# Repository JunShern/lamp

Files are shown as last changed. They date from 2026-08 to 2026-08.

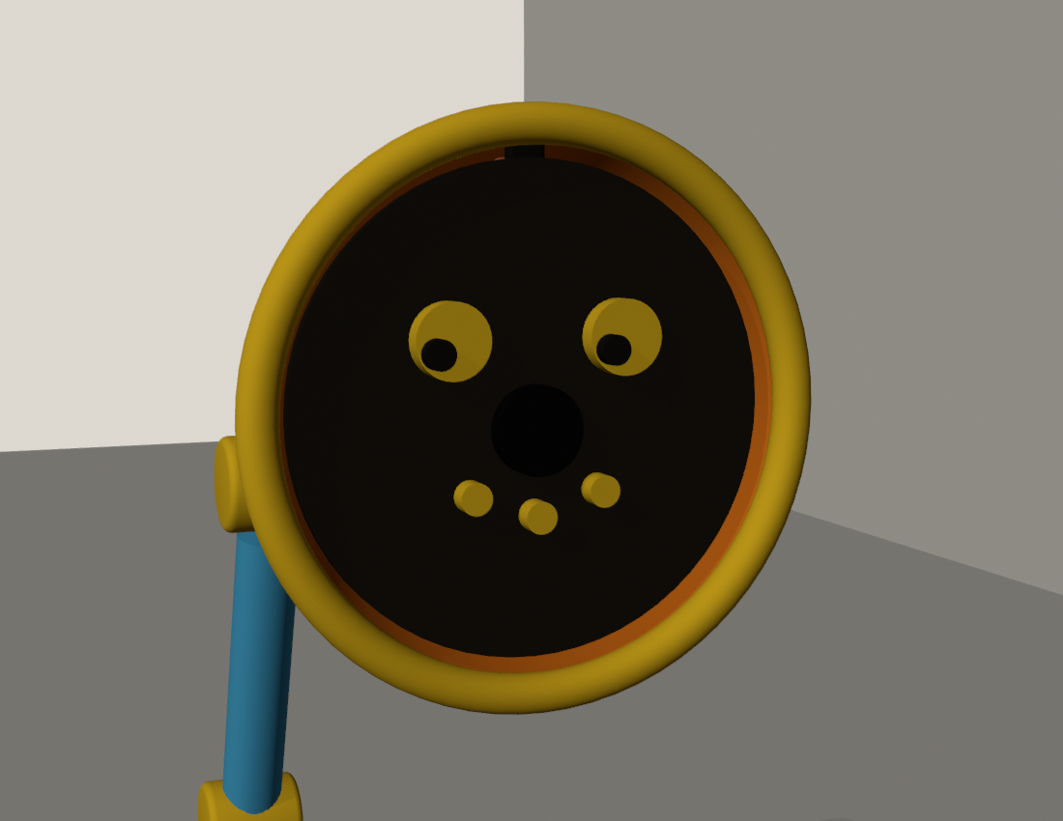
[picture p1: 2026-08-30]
cad/renders/lamp_duck_face.png

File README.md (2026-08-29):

# Lamp

A Pixar-style animatronic desk lamp: silent, expressive, and alive.

It listens (mic array), perceives without a camera (multizone time-of-flight),
thinks (Claude), and answers entirely through **motion**, a **16×16 projected
pixel display**, and **piezo chirps**. No voice, ever — the character is the
interface.

- **Design doc:** [docs/DESIGN.md](docs/DESIGN.md)
- **Bill of materials:** [docs/BOM.md](docs/BOM.md)
- **Status:** concept settled, design phase in progress.

## Repository layout (planned)

```
docs/       design doc, BOM, decisions
assets/     emotes, glyphs, chirps (JSON) — the shared contract
cad/        parametric Blender (bpy) model, renders, massing STLs
sim/        browser simulator (build: python3 sim/build.py)
lamp/       Python engine for the Raspberry Pi (validate: python3 -m lamp.validate)
tests/      pytest suite incl. envelope sweep (python3 -m pytest tests/)
```

The browser simulator and the Python engine implement the same spring/keyframe
physics over the same asset files and are cross-validated against each other —
what you tune in the simulator is what the hardware will do.

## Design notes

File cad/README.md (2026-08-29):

# CAD

`lamp_preview.py` — parametric massing model of the lamp, runnable headless
with Blender-as-a-module (`pip install bpy`). Builds the whole lamp in the
neutral pose from a single PARAMS dict (same joint angles as
`../assets/emotes.json`), renders design-review images (Workbench engine)
in three MicroDuck-inspired colourways, and exports massing STLs.

- `renders/` — design review renders
- `preview_stl/` — **massing shells only** — proportions and silhouettes for
  review, NOT print-ready engineering parts (no servo pockets, walls,
  fasteners, or clearances yet; those come in Phase 3)

Run: `python3 cad/lamp_preview.py`

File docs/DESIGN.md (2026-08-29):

# Design Document — Pixar-Style Animatronic Lamp

Status: **draft for review** · Last updated: 2026-08-29

## 1. Vision

A desk lamp with the soul of Luxo Jr.: a silent, expressive robot that lives on
a desk (or shelf), listens when spoken to, and responds only through **motion**,
a **projected 16×16 pixel display**, and **non-verbal piezo chirps**. Claude is
the mind; the body is the interface.

Guiding principles, in priority order:

1. **Motion quality is the product.** Anticipation, ease-in/ease-out, follow-through,
   secondary motion, gaze. A lamp that moves beautifully and does little beats a
   lamp that does everything and moves like a printer.
2. **Constraint is character.** 256 pixels and a piezo beeper are the *native
   medium*, not placeholders. The visual/sound language is designed for them.
3. **Privacy by physics.** No camera. Perception uses sensors that are
   incapable of producing imagery: a multizone time-of-flight depth sensor and
   a microphone array. Audio is processed on-device; only text leaves the lamp.
4. **Modular head.** The display module bolts to a standard interface so it can
   be swapped (light ring → matrix projector → anything else) without redesign.

Prior art worth stealing from: Pixar's *Luxo Jr.* (staging and timing), Apple's
**ELEGNT** research paper (Jan 2025 — expressive movement design for a
non-anthropomorphic lamp robot; strong taxonomy of functional vs. expressive
motion), and the SO-ARM100/101 open-source arms (proven low-cost serial-bus
servo mechanics).

## 2. Settled decisions

| # | Decision | Choice | Notes |
|---|---|---|---|
| D1 | Voice | **None.** Motion + projection + chirps only | Canonical Luxo behavior; removes TTS/latency pressure |
| D2 | Display | **Fine-pitch WS2812 matrix + projection lens**, likely final form. Grid = the panel's native resolution (16×16 minimum, likely 22×22) | Head interface stays modular as cheap insurance; all software resolution-parametric, glyph art finalized once the panel is verified in hand |
| D3 | Sound | **Passive piezo**, PWM-driven chirps | No speaker, no audio DAC; "Game Boy" palette |
| D4 | Camera | **Never in v1.** ToF depth grid + mic DOA only | Camera module possible later, with hardware shutter + power LED |
| D5 | Power | Mains, single external 12 V PSU into the base | No battery |
| D6 | Compute | Raspberry Pi 5 (8 GB) in the base | Headroom for local STT |
| D7 | Actuators | 5× Feetech ST3215 serial-bus servos (12 V, 30 kg·cm) | Position feedback, daisy-chain, ~£15 each |
| D8 | Size | ~40 cm tall upright, base ~180 mm ⌀ | Luxo Jr. presence, desk-friendly |
| D9 | Fabrication | Bambu Lab A1 (256×256×256 mm bed), PETG/PLA | Every part fits the bed; base prints in one piece |
| D10 | CAD | Blender with parametric `bpy` scripts in `cad/` | Regenerable geometry, STL export |
| D11 | Budget | £300–500 all-in | Current estimate ~£350, see BOM |

Open questions (fine to defer):

- O1 (direction settled, colourway open): shell design language follows
  Pollen Robotics' MicroDuck — matte pastel printed shell with **one warm
  saturated accent** on the mechanical hero parts (joint caps, shade rim,
  yaw disc), black reserved for optics, articulation honestly visible.
  Candidate colourways (see cad/renders/): cream `#F7E6CB`/orange (proposed),
  sky `#A9DBE8`/orange, graphite `#6C6A68`/yellow. A MicroDuck-style
  **REC-tally "listening" dot** on the shade lights only when the mic is
  live (hardwired to mic power, not software). Exact proportions still
  iterate in Blender.
- O2: Whether the shoulder needs spring counterbalance (decide after torque
  test on the bench; mounting bosses for a spring are designed in regardless).
- O3: Local STT (faster-whisper on the Pi) vs. cloud STT — start local for
  privacy; fall back if latency disappoints.

## 3. System overview

```mermaid
flowchart LR
    subgraph Head
        TOF[ToF 8x8 depth sensor]
        MATRIX[16x16 LED matrix]
        LENS[Projection lens + focus servo]
        PIEZO[Piezo chirper]
    end
    subgraph Arm
        S1[5x ST3215 bus servos]
    end
    subgraph Base
        MIC[USB mic array w/ DOA]
        PI[Raspberry Pi 5]
        PSU[12V PSU + 5V buck]
        DRV[Bus servo driver board]
    end
    MIC -->|"wake word + speech + direction"| PI
    TOF -->|I2C depth grid| PI
    PI -->|UART bus| DRV --> S1
    PI -->|SPI/PIO pixel data| MATRIX
    PI -->|PWM| PIEZO
    PI -->|PWM| LENS
    PI <-->|"text + tool calls only"| CLAUDE[(Claude API)]
```

The interaction loop:

1. **Idle**: subtle procedural "breathing" sway; occasional glances toward
   sounds (mic DOA) or motion (ToF deltas). Display shows a dim ambient face.
2. **Wake**: on-device wake word ("hey lamp" — final phrase TBD). The lamp
   *turns to face the speaker* (DOA angle → base yaw; ToF person-blob →
   head pitch) and perks up. Listening posture + listening glyph.
3. **Listen**: on-device STT transcribes. End-of-speech → acknowledgment nod +
   rising chirp, thinking posture + thinking animation. This staging absorbs
   Claude round-trip latency invisibly.
4. **Respond**: Claude returns a *performance* — a short choreography of
   emotes, display content, and chirps — which the behavior engine executes.
5. Return to idle.

## 4. Mechanical design

### 4.1 Kinematics — 5 DOF

| Joint | Axis | Range | Servo |
|---|---|---|---|
| J1 base yaw | vertical | ±150° | ST3215 |
| J2 shoulder pitch | horizontal | ~-10°…+95° | ST3215 |
| J3 elbow pitch | horizontal | ~±110° | ST3215 |
| J4 head pitch | horizontal | ~±90° | ST3215 |
| J5 head roll | along head axis | ±60° | ST3215 |

Link lengths (target): shoulder→elbow **160 mm**, elbow→wrist **160 mm**,
wrist→lens plane ~70 mm. Upright height ≈ 400–420 mm including base.

J5 (head roll) is what makes the "curious head-tilt" read; it lives in the
head assembly, so its servo mass sits at the worst lever arm — the head must
stay light (budget below).

### 4.2 Torque budget (worst case: arm horizontal, fully extended)

Assumptions: head module ≤ 220 g (matrix 35 g, lens 40 g, focus servo 15 g,
roll servo 60 g shared with J5, shell 70 g); forearm structure 80 g; elbow
servo + bracket 110 g.

Moment about the shoulder ≈ 0.22 kg·33 cm + 0.11 kg·16 cm + 0.08 kg·24 cm +
structure ≈ **11–13 kg·cm static**; ×2 dynamic margin → 22–26 kg·cm.
The ST3215 at 12 V stalls at ~30 kg·cm, so this is *feasible but warm* under
sustained horizontal poses. Mitigations, in order:

1. **Choreography rarely holds full horizontal extension** (neither does Luxo).
2. **Spring counterbalance** at the shoulder, anglepoise-style — an extension
   spring across the joint cancels most of gravity's moment. Authentic to the
   lamp archetype and lets the servo work only against inertia. Mounting
   bosses included in the print from day one (open question O2).
3. Torque-limit + temperature readback in software (the ST3215 reports load,
   temperature, and voltage), easing into thermal-safe poses.

### 4.3 Base

180 mm ⌀ × ~60 mm printed drum, weighted (steel washers / sand pocket) so
fast arm moves can't tip it. Houses: Pi 5, servo driver, 5 V buck, piezo of
last resort (main piezo is in the head), cable strain relief, and the J1 yaw
servo driving a printed ring gear or direct horn mount on a thin-section
lazy-susan bearing. Single external 12 V brick enters via a rear DC jack.

### 4.4 Head module interface

The wrist ends in a standard mount so display modules are swappable (D2):

- 4× M3 heat-set inserts on a 40×40 mm bolt pattern
- One 8-pin JST-XH pigtail: 5 V, GND, matrix data, piezo PWM, focus PWM,
  I²C SDA/SCL (ToF), spare
- Design rule: any head module ≤ 220 g, center of mass within 35 mm of the
  mount plane

The ToF sensor mounts in the head *beside the lens*, looking where the lamp
looks — so "what the lamp sees" and "where it projects" share a frame.

### 4.5 Printing (Bambu A1)

All parts ≤ 200 mm in the longest dimension except the base drum (≤ 250 mm,
fits diagonal-safe on the 256 mm bed). Shell parts in PLA (aesthetic, matte);
load-bearing joints and servo brackets in PETG. Heat-set M3 inserts
throughout; no support-heavy geometry — every part designed with a flat
print face. Multi-colour accents optional via AMS lite.

## 5. Display: the matrix projector

Optical chain: **WS2812B 16×16 matrix (10 mm pitch → 160×160 mm emitter…**
too large for the head — so the head uses a **smaller-pitch matrix**
(target: flexible 16×16 panels come in ~10 mm pitch; rigid mini-pitch panels
exist at 4–5 mm giving a 64–80 mm square, which is what the head shade
comfortably houses; final pick in BOM) → **diffuser sheet** (kills inter-LED
gaps, at slight sharpness cost — tune by trying 1–3 sheet thicknesses) →
**condenser/biconvex projection lens** on a printed sliding focus rail driven
by a micro servo.

- **Focus** is open-loop: ToF gives distance-to-surface, a calibration lookup
  table maps distance → rail position. At 256 px the depth of field is
  generous; ±10 % distance error is invisible.
- **Brightness**: theoretical max draw of 256 LEDs is ~15 A at 5 V — capped
  in firmware at 25–30 % global brightness (~3 A worst case, ~1 A typical).
  Desk projection at 30–60 cm is comfortable indoors; wall projection at
  1.5–2 m wants dim lighting. Acceptable for the character (D2).
- **Keystone**: with head pitch known from servo feedback and surface plane
  from ToF, the renderer pre-warps (integer row/column shifts at this
  resolution — cheap).
- **Also still a lamp**: a plain "all pixels warm white at safe brightness"
  mode gives real task lighting through the same lens.

The low-res visual language (to be developed in the simulator): a glyph set
(~emoji-like ideograms), 2-frame emotion faces, scrolling text (5×7 font),
meters/spinners, and a "thinking" animation family. The panel is WS2812B —
**full RGB per pixel** — so glyphs carry colour (blue rain, red heart,
green/red yes/no, rainbow spinner); the resting face stays warm amber as
the lamp's signature. Colour is defined per glyph in assets/glyphs.json. Framebuffer, simulator,
and glyph tooling are all grid-size-parametric; final glyph art is baked only
after the panel's true grid (16×16 vs 22×22) is confirmed on arrival.

## 6. Perception & privacy

### 6.1 Sensors

- **ST VL53L7CX** multizone ToF (head): 8×8 depth zones, 90° diagonal FoV,
  ~15 Hz, range to ~3.5 m. Used for: projection surface finding (least-squares
  plane fit over zones), throw distance (focus + brightness), person presence
  and rough position (blob vs. background), "don't blind anyone" check
  (never project at a face-height blob at close range).
- **USB mic array with onboard DSP** (base, e.g. ReSpeaker family): far-field
  capture, beamforming, noise suppression, and **direction of arrival**
  exposed over USB. Used for: wake word capture, STT audio, and turn-to-face
  behavior. No echo cancellation needed — the lamp has no voice.

### 6.2 Privacy invariants

1. **No camera exists in the device.** The ToF's 64 distance values cannot
   form an identifying image. (A future camera module would require a
   physical shutter and hardwired power LED — out of scope for v1.)
2. **Audio never leaves the device.** Wake word (openWakeWord/Porcupine-class,
   on-device) and STT (faster-whisper on the Pi 5) run locally. Only the
   *transcript* is sent to the Claude API. If local STT proves too slow we
   revisit explicitly (open question O3) — it is a design change, not a knob.
3. **Hardware mic mute** switch on the base, cutting the array's USB power.
   Muted state shown on the display. A REC-style tally dot on the shade is
   hardwired to mic power: lit means listening, dark means physically off.
4. No audio/depth recording to disk; rolling buffers only, in RAM.

## 7. Sound: the piezo chirp language

Passive piezo disc driven by hardware PWM through a transistor (one GPIO).
Synthesizable parameters: pitch (~200 Hz–8 kHz), duration, pitch envelope
(chirp up/down/trill), amplitude envelope (via PWM duty), rhythm. A named
"sound font" — `ack`, `curious`, `happy`, `sad`, `alert`, `snore`, … — each a
~10-line envelope spec, triggerable by the behavior engine and by Claude.
Chirps accompany motion accents (never continuous noise).

## 8. Electronics & power

```
[12V 8A external brick]
   ├── 12V rail → bus servo driver → 5× ST3215 (daisy-chain)
   └── 12V→5V 6A buck
         ├── Raspberry Pi 5 (via USB-C or GPIO header power)
         ├── LED matrix (firmware-capped ~3A)
         ├── VL53L7CX (I²C, 3V3 via Pi)
         └── focus micro-servo, piezo driver
```

- Servo bus: Pi UART ↔ Waveshare/Feetech serial bus driver board (TTL
  half-duplex). All five joints on one 3-wire daisy chain.
- Matrix data: WS2812 single-wire protocol from the Pi (SPI-driven, e.g.
  `pi5neo`/`rpi-ws281x`-class library with a 3.3→5 V level shifter).
- Wiring through the arm: the 8-pin head pigtail + servo chain routed through
  printed cable channels in the links; service loops at each joint.
- Kill behavior: watchdog in the daemon — on crash, servos go torque-off
  (lamp slumps gracefully rather than freezing rigid; also endearing).

## 9. Software architecture

One Python daemon (`lamp/`) on the Pi, systemd-managed, structured as
processes/async tasks around a shared state bus:

- **perception**: wake word, streaming STT (faster-whisper), mic DOA reader,
  ToF plane/person tracker.
- **behavior**: the character state machine (idle / orienting / listening /
  thinking / performing / resting). Owns *what the lamp does*; degrades
  gracefully offline (no API ⇒ still a living lamp, just nonverbal).
- **animation**: 50 Hz pose interpolator — keyframed emotes + procedural
  layers (breathing, gaze tracking via simple 2-joint IK, micro-fidgets),
  easing curves, torque/temperature guards. Servo abstraction over the bus.
- **display**: 16×16 framebuffer, glyph/font/animation assets, keystone warp,
  brightness governor, focus controller.
- **sound**: chirp synthesizer (PWM envelopes), sound font.
- **brain**: Claude integration (below).
- **sim**: a desktop simulator (side-view lamp rig + matrix preview + chirp
  audio) so character work starts before hardware exists and regression-tests
  choreography after.

### 9.1 Claude integration

Python `anthropic` SDK, Messages API, default model **`claude-opus-5`**
(configurable; adaptive thinking on by default, `output_config.effort` set
low/medium for snappy conversational turns — the transcript in, performance
out loop is not a hard reasoning task). Streaming on, so choreography can
begin as soon as the first tool call arrives.

Claude receives: the transcript, recent conversation history, and a compact
world state (person present/direction, current pose, surface type, time of
day). The system prompt frames Claude as *the lamp* — a mute, curious
character who communicates in gesture and glyphs, with tools:

- `perform(script)` — a timed sequence of steps, each combining
  `emote(name, intensity)`, `display(glyph | text | animation)`,
  `chirp(name)`, `look_at(person | surface | object_direction)`. The
  animation engine compiles it; the API returns one performance per turn.
- `set_lamp_state(...)` — task-light mode, brightness, do-not-disturb.

Long-form answers ("what's the weather this week?") become glyph + short
scrolling-text performances; the prompt explicitly rewards brevity and
pictograms over prose. System prompt and tool definitions stay byte-stable
for prompt caching; volatile world state rides in the user turn.

## 10. Build phases

| Phase | Deliverable | Exit criterion |
|---|---|---|
| 0 Concept | this document | user sign-off ✅ |
| 1 Order & simulate | BOM ordered; `sim/` running; emote library v0; glyph font v0 | 10 emotes + 15 glyphs reviewable on screen |
| 2 Bench bring-up | servos moving on the bus with eased motion; matrix projecting through hand-held lens; chirps; ToF plane fit demo | "breathing" motion on a bare servo chain; legible 1 m projection |
| 3 Body | Blender CAD, printed arm + base, assembled, cable-routed | lamp holds poses, no overheat in 30 min idle choreography |
| 4 Senses | wake word → orient → listen → transcript, all on-device | says-my-name test from 3 m, 90 % orient accuracy |
| 5 Mind | Claude performances end-to-end; personality tuning | ask it something; it answers charmingly in ≤ 3 s to first motion |
| 6 Polish | shell aesthetics, sound font, idle-life richness, task-light UX | it lives on the desk and you stop noticing the machinery |

Phase 1 starts only after BOM review (docs/BOM.md, UK-sourced, in progress).

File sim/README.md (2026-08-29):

# Simulator

Browser-based character sandbox for the lamp. Everything it plays comes from
`../assets/*.json` — the same data the Pi daemon will consume.

- `template.html` — the app, with an `__ASSETS_JSON__` placeholder
- `build.py` — validates the asset files (grid sizes, joint limits, time
  ordering, referenced glyph/chirp names) and inlines them → `dist.html`
- `dist.html` — open in any browser, no server needed

Build: `python3 sim/build.py`

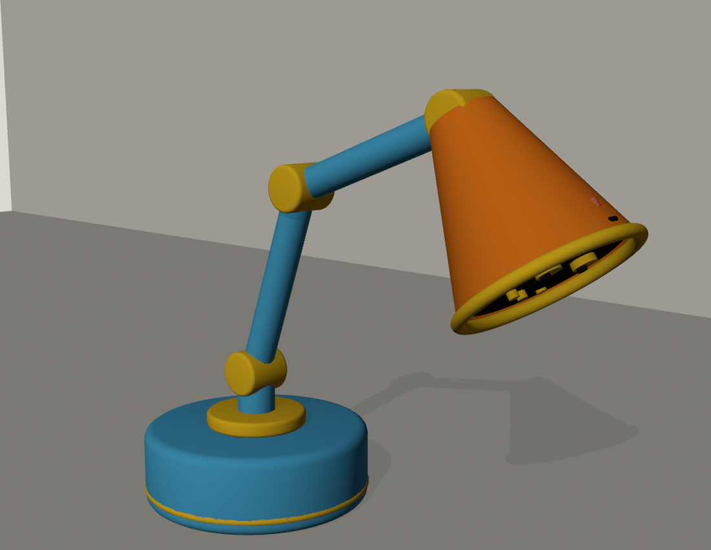
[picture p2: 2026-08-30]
cad/renders/lamp_duck_hero.png

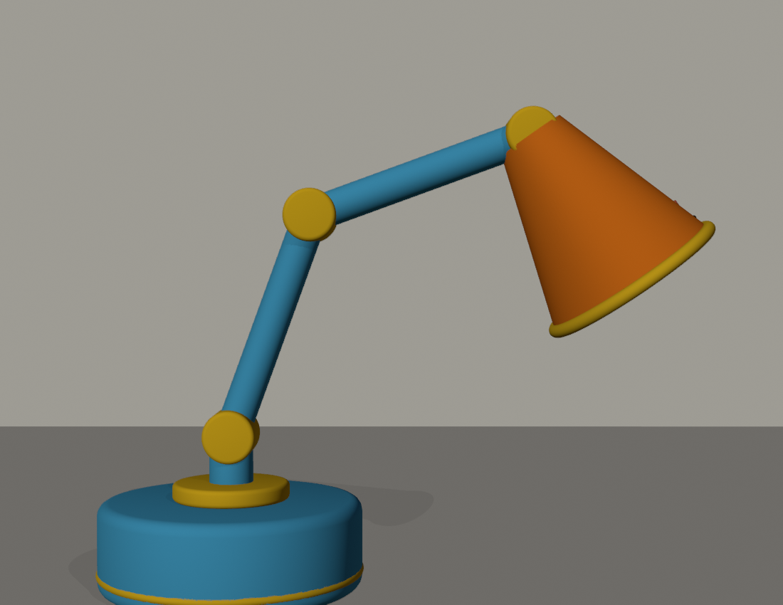
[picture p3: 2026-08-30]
cad/renders/lamp_duck_side.png

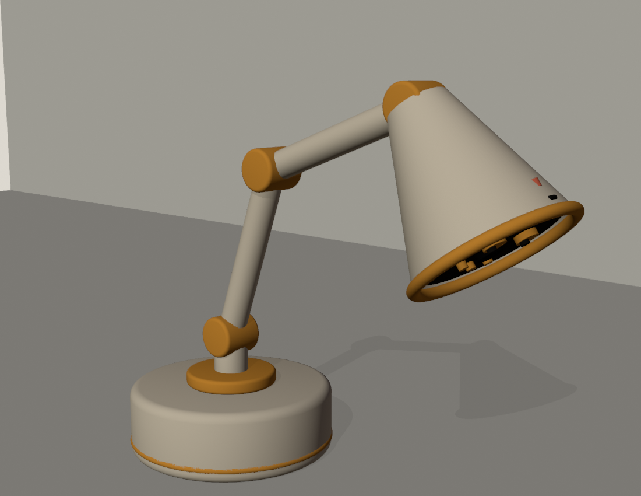
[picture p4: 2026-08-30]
cad/renders/lamp_cream_hero.png

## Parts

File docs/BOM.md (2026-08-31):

# Bill of Materials — UK Sourcing

Researched 2026-08-29, delivery to London. Prices verified on the day unless
marked *(unverified)* — Amazon UK and some distributor pages block automated
price checks; those show typical street prices.

## Core electronics

| Item | Pick | Price | Supplier | Notes |
|---|---|---|---|---|
| Servos ×5 | Feetech/Waveshare **ST3215 12 V, 30 kg·cm** | £21.75 ea (£108.75) | [Waveshare official eBay UK store](https://www.ebay.co.uk/itm/265782094249) | Ships Shenzhen, ~6–12 days. **Value path:** WowRobo/AliExpress 5-pack ≈ £12–14/servo (~£65), 1–2 wk wait |
| Servo driver | **Waveshare Serial Bus Servo Driver HAT (A)** | £18.30 | [The Pi Hut](https://thepihut.com/products/serial-bus-servo-driver-hat-for-raspberry-pi-with-esp32) | In stock. Sits on Pi header, 9–25 V in, drives whole ST-series chain, **onboard 5 V buck can power the Pi** |
| Compute | **Raspberry Pi 5 8 GB** | £168.00 | [The Pi Hut](https://thepihut.com/products/raspberry-pi-5) | In stock. ⚠ RAM-shortage-era pricing. Pimoroni lists **£140 but out of stock** — watch for restock. microSD ~£10 extra |
| Pi PSU (bench/dev) | Official 27 W USB-C | £11.50 | [The Pi Hut](https://thepihut.com/products/raspberry-pi-27w-usb-c-power-supply) | Optional in final build (HAT powers Pi from 12 V) |
| Cooling | Active Cooler for Pi 5 | £4.80 | [The Pi Hut](https://thepihut.com/products/active-cooler-for-raspberry-pi-5) | In stock |
| Mic array | **ReSpeaker XMOS XVF3800 USB 4-mic** | £52.80 | [The Pi Hut](https://thepihut.com/products/respeaker-xmos-xvf3800-ai-powered-4-mic-array-for-clear-voice-even-in-noise) | In stock. DOA exposed over USB (`AEC_AZIMUTH_VALUES` via host_control), VAD, LED ring. **v2.0 (XVF-3000) is discontinued** — don't chase it. ReSpeaker Lite is 2-mic (left/right only), not suitable |
| ToF sensor | **Pololu VL53L7CX carrier** (8×8, 60°×60° FoV, 350 cm) | £19.20 | [The Pi Hut](https://thepihut.com/products/vl53l7cx-time-of-flight-8x8-zone-wide-fov-distance-sensor-carrier-with-voltage-regulator-350cm-max) | In stock. Budget alt: Pimoroni VL53L5CX £16.25 (narrower 45°×45°) |
| Piezo | **PS1240** + enclosed piezo element | £1.30 + £0.90 | [The Pi Hut](https://thepihut.com/products/piezo-buzzer) | In stock. Optional PAM8904 driver amp £4.80 for louder chirps |

## Display module

Single-panel strategy: buy only the fine-pitch panel the head will actually
use, and bench-test optics directly on it. (Optics calibration — focal
length, lens distance, diffuser gap, focus LUT — is specific to the panel's
physical size, so nothing done on a cheap 10 mm-pitch panel would transfer;
the general gotchas below are already settled by prior art.)

| Item | Pick | Price | Supplier | Notes |
|---|---|---|---|---|
| Head matrix | **BTF WS2812B-2427 mini flexible panel** (fine pitch) | $50.99 (~£40) | [BTF direct](https://www.btf-lighting.com/products/ws2812b-mini-led-smd-2427-digital-11x44-22x22-digital-flexible-led-panel-screen-individually-addressable-dc5v) | 1–2 wk from China. Comes as 22×22/11×44 — order the 22×22 and use its **full native grid** (more pixels = better; software is grid-parametric). Verify pitch/layout on arrival. **Fallback if it disappoints:** rigid 16×16 boards on AliExpress ~£10–18, ordered later |
| Projection lens | 100 mm double-convex glass lens | £13.20 | [eBay UK "lens-store"](https://www.ebay.co.uk/sch/i.html?_nkw=100mm+biconvex+lens+condenser) | Many diameter/FL combos in stock |
| Fresnel | A4 Fresnel page-magnifier sheet | ~£4–8 *(unverified)* | Amazon UK / [magnifyingglasses.co.uk](https://magnifyingglasses.co.uk/product-category/page-sheet-magnifiers/) | Grooved side toward the wall |
| Diffuser | LED diffuser sheet / thin acrylic | ~£5 | Amazon UK | See optics gotcha below |
| Focus servo | any 9 g micro servo | ~£4 | Amazon UK / Pi Hut | Slides lens on printed rail |

**Optics gotchas from prior art** ([WS2812 8×8 projector on Printables](https://www.printables.com/model/1470198-ws2812-8x8-projector),
[Hackaday coverage](https://hackaday.com/2025/11/07/an-led-projector-as-a-lighting-effect/),
[Ikea projection lamp conversion](https://hackaday.com/2016/06/14/projection-lamp-makeover-adds-led-matrix-and-raspberry-pi-zero/)):

1. A sharp lens images the **LED dies themselves** — 256 tiny rectangles.
   A mild diffuser (or a printed per-LED lens array) makes soft round pixels.
2. **Mirror/flip the image in software** — projection inverts it.
3. Match Fresnel size to panel size or the corners vignette.

## Power

| Item | Pick | Price | Supplier | Notes |
|---|---|---|---|---|
| Main PSU | **Mean Well GST60A12-P1J** desktop brick, 12 V/5 A | £23.00 | [The Pi Hut](https://thepihut.com/products/meanwell-12v-5a-60w-power-supply-gst60a12-p1j) | In stock. Sealed brick — no mains wiring in the build. 60 W is fine with firmware torque/current limits |
| LED buck | Waveshare 6–14 V → 5 V/8 A | £8.40 | [The Pi Hut](https://thepihut.com/products/dc-dc-buck-converter-6-14v-to-5v-8a) | In stock. Dedicated to matrix; HAT's own buck feeds the Pi |

(Higher-headroom alt: Mean Well LRS-100-12, 12 V/8.5 A, ~£23 on eBay UK — but
it's an enclosed-frame PSU needing a fused IEC inlet; the brick keeps mains
out of the printed base.)

## Mechanical

| Item | Price | Supplier |
|---|---|---|
| 25T servo horn set (ST3215 spline is 25T/⌀5.9 mm) | £2.40 (metal £3.10) | [The Pi Hut](https://thepihut.com/products/standard-servo-arm-and-horn-set-25-spline) |
| 120 mm aluminium lazy-susan bearing (base yaw) | ~£8–12 *(unverified)* | Amazon UK / eBay UK |
| 608ZZ bearings ×4 (printed-ring alternative) | £6.70 | [The Pi Hut](https://thepihut.com/products/radial-ball-bearing-608zz-set-of-4) |
| M3 heat-set inserts, 50-pack | £5.90 | [The Pi Hut](https://thepihut.com/products/brass-heat-set-inserts-for-plastic-m3-x-3mm-50-pack) |
| M3 screw/nut assortment kit | ~£13–17 *(unverified)* | Amazon UK |
| Anglepoise spring kit (counterbalance, O2) | ~£15–25 | [anglepoise.com](https://www.anglepoise.com/product/original-1227-spring-kit/) / eBay UK |
| Filament: PLA (shell) + PETG (joints) | ~£30 | usual suspects |

## Totals

**Chosen path (2026-08-29): patient** — China lead times are fine, single
fine-pitch panel only.

| Path | Servos | Pi 5 | Everything else | Total |
|---|---|---|---|---|
| Fast (eBay UK servos, Pi Hut Pi) | £109 | £168 | ~£278 | **~£555** |
| Mixed (multipack servos, Pi Hut Pi, skip bench PSU) | ~£68 | £168 | ~£262 | **~£498** |
| **Patient — chosen** (multipack servos, Pimoroni Pi restock) | ~£68 | £140 | ~£250 | **~£458** |

The single biggest line is the Pi 5 8 GB at current shortage pricing. Levers:
catch the Pimoroni restock (−£28), drop to 4 GB (fine for our workload if
faster-whisper uses the small model; −£60 when stocked), or use any Pi 5
already owned.

## Akihabara option (researched 2026-08-31)

Verified in-person alternatives while in Tokyo: **Akizuki Denshi** stocks the
Feetech **STS3215 7.4 V / 19.5 kg·cm** (¥3,200, 13 on the Akihabara shelf,
2F shelf 72) plus the **FE-URT-1** bus driver, 5 V/6 A bucks, piezo discs and
JST pigtails — a same-day Phase-2 bench kit. Voltage trade-off: 7.4 V halves
torque headroom vs the 12 V/30 kg·cm variant (validated emote peak is
8.0 kg·cm, so choreography fits with 2.4x margin; worst-case dragged poses
~13 kg·cm lean on the shoulder spring, O2). Don't mix variants on one bus
rail. Skip in Japan: ToF breakouts (no Akiba retail), Pi 5 (no longer
cheaper: ~¥33,900 ≈ £173), AC PSU bricks (100 V/Type-A — unsafe on UK 230 V
unless labelled 100–240 V). Check shelves: Shigezone (Radio Depart 1F) for
WS2812 matrices; Marutsu counter for ReSpeaker XVF3800 (¥9,149 warehouse).
Vstone Robot Center and Tsukumo Robot Kingdom are both closed.

## Borrow-from list (open source prior art)

- **[LeLamp](https://github.com/humancomputerlab/LeLamp)** — open-source
  expressive lamp robot explicitly based on Apple's ELEGNT paper: 5 axes,
  STS3215 servos + Pi, ~$260 BOM, GPL-3.0. **Closest existing project to
  ours** — review its mechanics and motion stack before CAD (license: we can
  study it freely; if we *derive* code/CAD from it, that portion is GPL).
- [SO-ARM100/101](https://github.com/TheRobotStudio/SO-ARM100) — servo
  configs, wiring, CAD for the STS3215 chain.
- [Luci](https://github.com/jochenalt/Luci) — older Pixar-lamp robot,
  mechanics reference.
- [Cornell ECE5725 Pixar Lamp](https://courses.ece.cornell.edu/ece5990/ECE5725_Fall2019_Projects/Dec_04_Demo/Pixar_Lamp/Website/index.html)
  — Pi-based Luxo social robot course project.

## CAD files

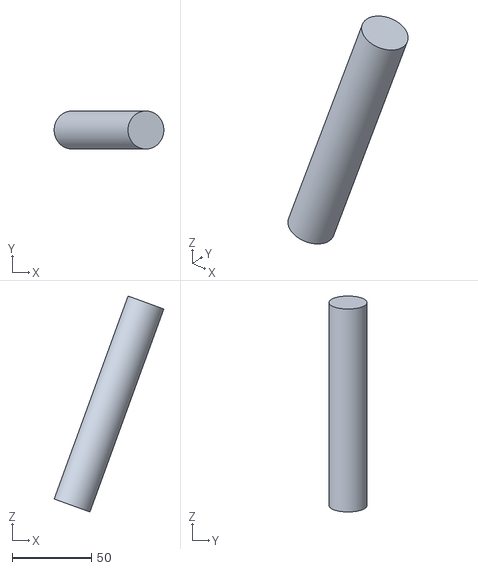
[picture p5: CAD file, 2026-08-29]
cad/preview_stl/arm_lower.stl
69.1 x 24.0 x 136.0

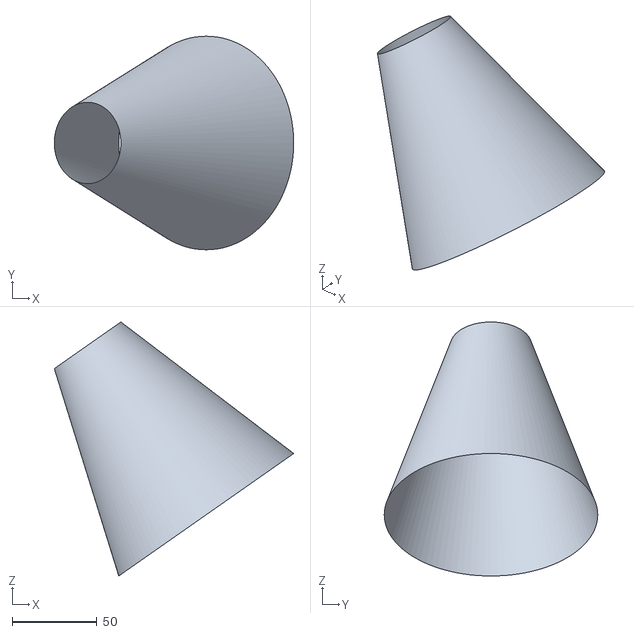
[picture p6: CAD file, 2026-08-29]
cad/preview_stl/head_shade.stl
141.2 x 126.0 x 149.8

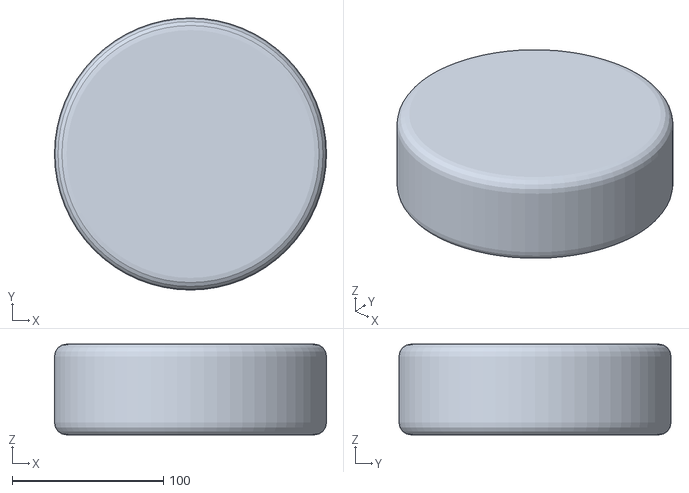
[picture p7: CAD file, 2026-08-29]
cad/preview_stl/base_drum.stl
180.0 x 180.0 x 60.0

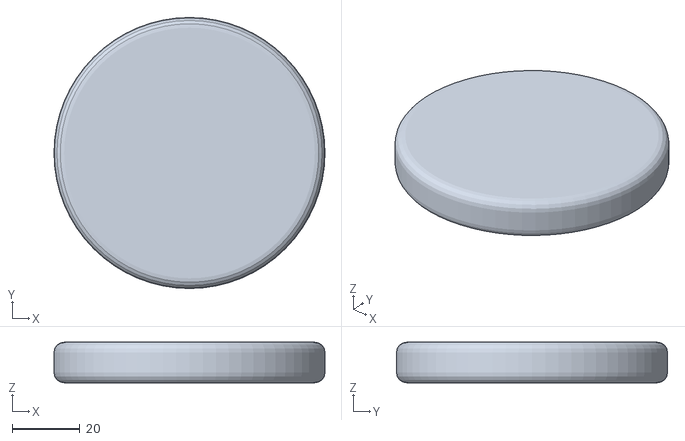
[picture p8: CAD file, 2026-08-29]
cad/preview_stl/yaw_disc.stl
80.0 x 80.0 x 12.0

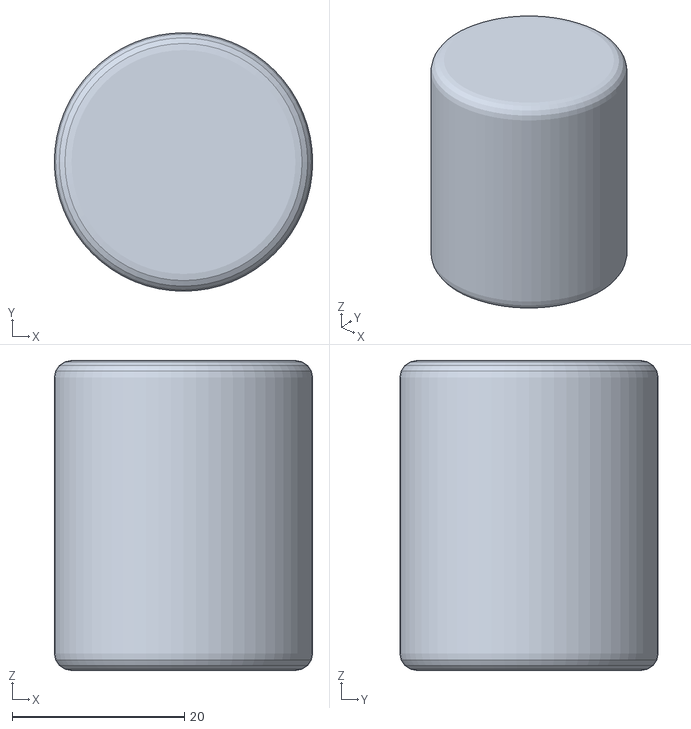
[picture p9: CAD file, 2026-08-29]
cad/preview_stl/shoulder_tower.stl
30.0 x 30.0 x 36.0

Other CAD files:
cad/preview_stl/arm_upper.stl

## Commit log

2026-08-29 Add design doc: concept, architecture, and build plan for animatronic lamp
    Concept settled in discussion: silent 5-DOF Pixar-style lamp, 16x16
    LED-matrix projector head, piezo chirps, camera-free perception (multizone
    ToF + mic array DOA), Raspberry Pi 5 + Claude brain, Blender-scripted CAD
    for a Bambu A1. BOM with UK sourcing to follow.
    Claude-Session: https://claude.ai/code/session_01Qam7eha1JDBQRpL5sE9a3t
2026-08-29 Add UK-sourced bill of materials with verified prices
    Verified suppliers/prices for servos, driver HAT, Pi 5, XVF3800 mic array
    (v2.0 is discontinued), VL53L7CX ToF, matrix panels (two-panel strategy for
    the fine-pitch head display), optics with prior-art gotchas, power, and
    mechanical parts. Three cost paths: ~GBP 455-575. Adds open-source
    borrow-from list (LeLamp, SO-ARM100, Luci).
    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
2026-08-29 Drop 10mm bench panel; lock patient sourcing path
    Optics calibration (focal length, lens distance, diffuser gap, focus LUT)
    is specific to panel size, so a 10mm-pitch bench panel yields no
    transferable results; general projection gotchas are already settled by
    prior art. Single fine-pitch panel, with a cheap rigid 16x16 as a
    later-order fallback. Patient path total ~GBP 458.
    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
2026-08-29 Display grid = panel's native resolution, not a hard 16x16
    Windowing a 22x22 panel down to 16x16 would waste pixels for no physical
    reason. D2 amended: grid is the panel's native resolution (16x16 minimum,
    likely 22x22); framebuffer, simulator and glyph tooling stay
    grid-size-parametric, glyph art baked after the panel is verified on
    arrival.
    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
2026-08-29 Phase 1: asset library + browser simulator
    assets/: emotes (12), glyphs (15), chirps (9) as JSON - the shared contract
    for the simulator now and the Pi daemon later. sim/: mm-accurate side-view
    simulator with live projection targeting, gravity-torque readout from the
    mass model, matrix display (16/22 grid, glyph/anim/scroll modes), WebAudio
    piezo chirp synth, mic-DOA turn-to-face dial, puppet sliders, and four
    performance scripts of the kind Claude's perform() tool will emit. Build
    script validates assets against joint limits (caught one overshoot).
    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
2026-08-29 Parametric CAD massing model with design renders
    Headless Blender (bpy) script builds the full lamp from one PARAMS dict in
    the emotes.json neutral pose: weighted base with accent ring, two-link arm
    with orange servo joint caps, open shade with rim, dark face plate, black
    lens-eye, pixel-dot face, ToF window, REC-style listening indicator and
    rear hardware mute switch. Design language per Pollen Robotics MicroDuck
    research: matte pastel shell + one warm accent, black only for optics.
    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
    [arm_lower.stl, arm_upper.stl, base_drum.stl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]
2026-08-29 Sim iteration: make the lamp lovable
    Styled body in the scene (cream shell, orange joint caps and accents,
    REC dot) with the live LED framebuffer drawn as the lamp's face in the
    shade. Under-damped spring layer on every joint for overshoot and settle.
    The lamp now gaze-tracks your cursor, blinks, does random idle
    micro-behaviours (glances, stretches, curious dips), falls asleep when
    ignored and wakes with a stretch, reacts to petting its head (happy
    wiggle + heart) and booping its base (startle). Display returns to the
    resting face after showing a glyph. Soft light-cone fill on projection.
    Claude-Session: https://claude.ai/code/session_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
2026-08-29 Sim iteration: projected glyph on desk + emote validation engine
    The light patch now renders the live framebuffer as foreshortened pixels
    on the desk - the projector-as-voice concept made visible. New validation
    panel sweeps all 12 emotes through the spring engine headlessly at 120Hz
    and reports peak joint speed vs the ST3215's ~270 deg/s spec, peak
    shoulder torque vs the 15 kg-cm sustained-safe line, and joint-limit
    grazes: currently 12/12 inside the servo envelope (peak 161 deg/s, peak
    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
2026-08-29 Cuteness iteration: living face with tracking pupils, wave emote, big-head CAD
    Resting display is now a procedural face - large dim-lit eyes whose bright
    pupils follow the cursor, blinks, small smile - replacing the static glyph
    (kindchenschema pass). New wave_hello emote with anticipation, tuned to
    pass validation (13/13 emotes inside the servo envelope). Chirps softened.
    Scene head panel enlarged. CAD: shade grown to r63/len122 with slimmer arm
    for Luxo-like head-heavy proportions; physical pixel face reworked to big
    eyes with viewer-facing pupils and button-nose lens; renders regenerated.
    Claude-Session: https://claude.ai/code/sessio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
    [arm_lower.stl, arm_upper.stl, head_shade.stl]
2026-08-29 Sim iteration: grab-and-drag IK, squash & stretch, yawn-to-sleep with zzz
    Grab the head and drag it - two-link IK follows the hand while the face
    keeps its world angle, springs snap it home on release with a happy chirp
    (a tap still pets). Head squashes/stretches with arm speed (classic
    principle). Falling asleep now goes yawn (new glyph) -> settle -> snore,
    with drifting z's drawn above the shade. Grab/grabbing cursors, no text
    selection during drag. Validation still 13/13.
    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
2026-08-29 Python animation engine, cross-validated against the browser simulator
    lamp/ package: keyframe evaluation, under-damped spring rig, forward
    kinematics, gravity-torque model, and the emote envelope sweep - a
    behavioural mirror of the sim engine, consuming the same assets/*.json.
    python3 -m lamp.validate reports the envelope (13/13 ok); pytest suite
    covers kinematics known-values, envelope, and asset integrity. Cross-check
    vs the browser engine agrees within 0.5 deg/s and 0.05 kg.cm on every
    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
2026-08-29 Full 3D simulator view with strong MicroDuck colourways
    Three.js articulated lamp built from the same parametric dimensions as the
    CAD model, driven by the identical spring engine and assets: orbit + zoom,
    click-to-pet via raycast, live face texture in the shade, projected glyph
    drawn in light on the desk with a translucent cone, soft shadows, squash
    and stretch. Colourway switcher (duck sky/orange/yellow default, lavender,
    cream, graphite) applied across 3D and the schematic view, per user
    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
2026-08-29 Full-RGB display language
    The WS2812B panel is RGB per pixel, so the glyph format now carries colour:
    a glyph is either a plain row array (amber) or {color, palette, rows} for
    multi-colour art. Coloured set: yellow sun/alert, pale moon, white cloud
    with blue raindrops, red heart, green yes, red no, purple note, blue zzz,
    teal listening, rainbow spinner. Framebuffer cells carry colour+intensity
    through all four render paths (matrix, 2D face, desk patch, 3D texture).
    Resting face stays signature amber. Fixed glyph/scroll buttons being
    instantly reverted by the face-restore timer. Validators and tests updated
    for the new glyph format.
    Clau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
2026-08-30 Duck colourway CAD renders; wall projection in 3D sim
    CAD colourways gain separate body/shade/accent roles; duck (sky/orange/
    yellow) is now primary with lavender and cream alternates, renders
    regenerated. 3D scene gains a single-sided wall: the beam and glyph land
    on it when the head points up-forward, matching the design's desk-or-wall
    requirement.
    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
2026-08-31 BOM: Akihabara in-person sourcing option
    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
